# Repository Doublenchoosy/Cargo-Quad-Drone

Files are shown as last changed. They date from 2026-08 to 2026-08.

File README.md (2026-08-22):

# Printable frame parts

Three parts, sized to the exact components from the shopping list:

- **center_plate** — mounts the SpeedyBee F405 V4 stack (30.5mm hole pattern) and cradles the inboard end of each carbon tube arm.
- **motor_mount** — print 4 of these. Clamps to the outboard end of each tube and has the 19x19mm M3 bolt pattern for the iFlight 3112 motor, plus a center hole for the motor wires.
- **payload_deck** — carries the Raspberry Pi (standard 58x49mm hole pattern) on standoffs run down through the same 30.5mm pattern as the center plate, so one style of M3 standoff works the whole stack.

## Print settings
- Material: PETG (handles vibration and heat better than PLA — motors and ESCs get warm)
- Walls: 4 (center_plate, motor_mount — these carry flight loads), 3 is fine for payload_deck
- Infill: 25-30% gyroid or grid for center_plate/motor_mount, 15% for payload_deck
- Orientation: print flat as-is, no supports needed
- Consider M3 heat-set inserts for the stack and motor bolt holes if you'll be removing those screws often — not needed for the small zip-tie holes

## Tube arms
Get the **10x12x440mm** carbon tube (12mm OD), 4 pieces. Dry-fit the center plate and all 4 motor mounts on the tubes first, slide the motor mounts in/out until the motor-to-motor diagonal spacing is around 580-620mm, then mark, add a dab of thick CA glue or epoxy in each cradle groove, and zip-tie both ends of every tube through the small holes flanking the groove. Let the glue cure before your first flight. 330mm leaves about 70mm of slack per tube for this tuning step — no need for the longer 420mm version.

## Files
- `*.scad` — source, editable in the free OpenSCAD app if any of your actual parts differ slightly (open the file, change the variable at the top, e.g. `stack_span`, and re-render)
- `*.stl` — ready to slice and print as-is

## DYS F7 F772 Wire orientation
Screenshot 2026-08-21 at 11 17 44 PM

## AM32 ESC Wire orientation
Screenshot 2026-08-21 at 11 25 01 PM

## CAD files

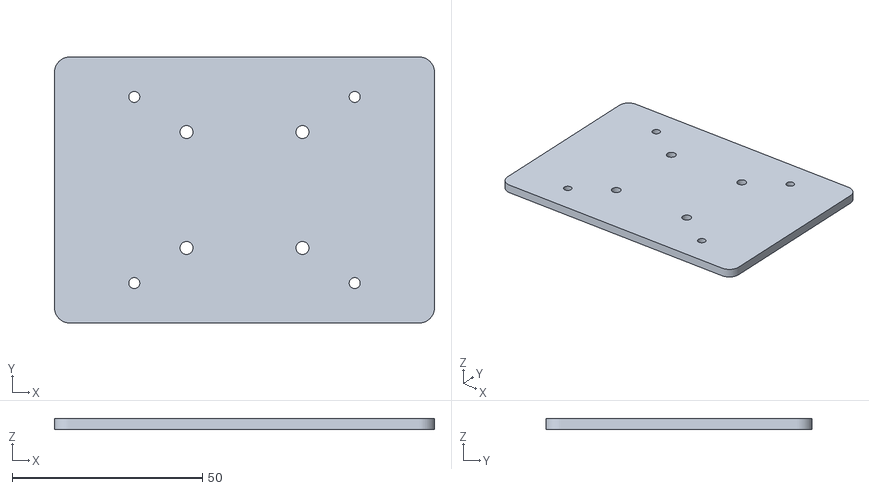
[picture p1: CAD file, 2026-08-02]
payload_deck.stl
100.0 x 70.0 x 3.00

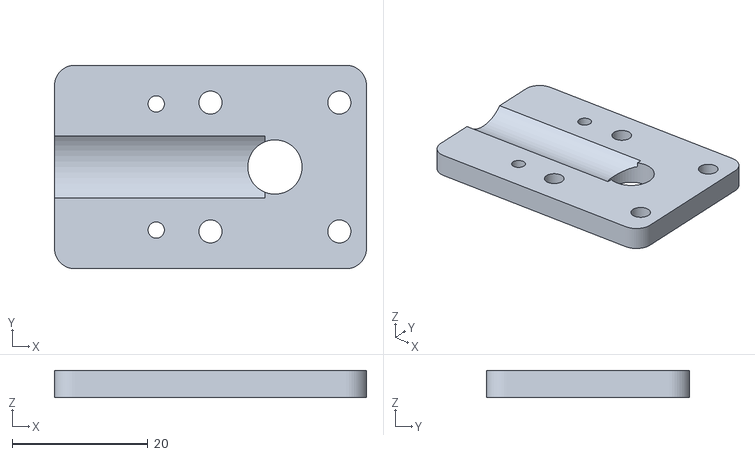
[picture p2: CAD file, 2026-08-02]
motor_mount.stl
46.0 x 30.0 x 4.00

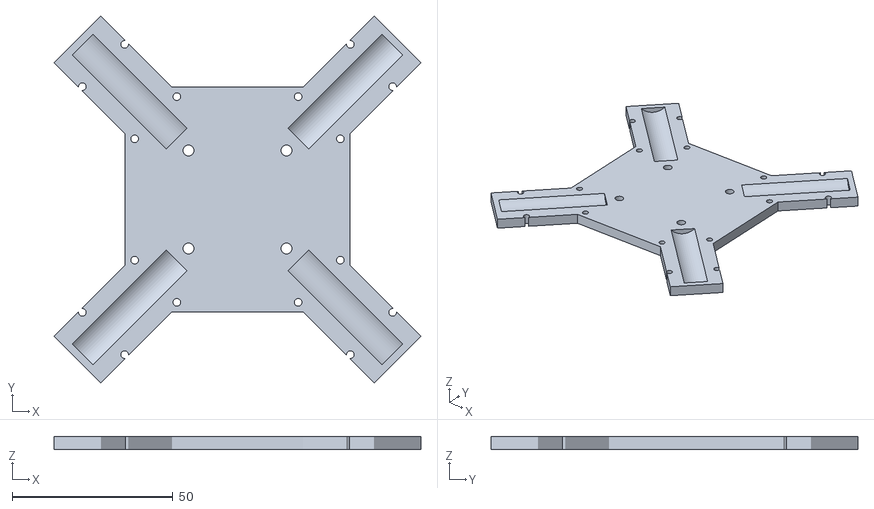
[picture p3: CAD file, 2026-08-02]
center_plate.stl
114.3 x 114.3 x 4.00

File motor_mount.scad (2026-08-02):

$fn = 48;

// ---- Parameters ----
plate_t      = 4;
tube_d       = 12.6;
mount_span   = 19;    // iFlight NIDICI 2812 motor bolt pattern (19x19mm)
motor_hole_d = 3.4;   // M3 clearance
wire_hole_d  = 8;      // center hole for motor wires
plate_len    = 46;     // length of the mount plate (tube clamp + motor face)
plate_w      = 30;     // wide enough for the 19mm motor bolt pattern with edge margin
groove_depth = 2;

module base_plate() {
    hull() {
        for (x = [-1,1]) for (y = [-1,1])
            translate([x*(plate_len/2-3), y*(plate_w/2-3), 0])
                cylinder(r=3, h=plate_t);
    }
}

module tube_channel() {
    translate([-plate_len/2 + plate_w/2, 0, plate_t - groove_depth + tube_d/2])
        rotate([0,90,0])
            cylinder(d=tube_d, h=plate_w+2, center=true);
}

module tie_holes() {
    for (yp = [-1,1])
        translate([-plate_len/2 + plate_w/2, yp*(tube_d/2+3), -1])
            cylinder(d=2.4, h=plate_t+2);
}

module motor_holes() {
    mx = plate_len/2 - mount_span/2 - 4;
    for (x = [-1,1]) for (y = [-1,1])
        translate([mx + x*mount_span/2, y*mount_span/2, -1])
            cylinder(d=motor_hole_d, h=plate_t+2);
    translate([mx, 0, -1])
        cylinder(d=wire_hole_d, h=plate_t+2);
}

difference() {
    base_plate();
    tube_channel();
    tie_holes();
    motor_holes();
}

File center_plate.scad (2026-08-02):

$fn = 48;

// ---- Parameters (edit these to match your exact parts) ----
plate_t     = 4;      // plate thickness (mm) - PETG recommended
hub         = 70;     // central hub square size (mm)
stack_span  = 30.5;   // SpeedyBee F405 V4 stack hole spacing (mm)
mount_d     = 3.4;    // M3 clearance hole
root_len    = 46;     // length of each arm root stub, from hub edge (mm)
tube_d      = 12.6;   // 12mm carbon tube OD + printing fit clearance
stub_w      = tube_d + 8;  // width of each root stub
tie_d       = 2.4;    // zip-tie hole diameter
wall_case   = 3;       // corner rounding radius

module hub_plate() {
    hull() {
        for (x = [-1,1]) for (y = [-1,1])
            translate([x*(hub/2-wall_case), y*(hub/2-wall_case), 0])
                cylinder(r=wall_case, h=plate_t);
    }
}

module arm_stub(angle) {
    rotate([0,0,angle])
        translate([hub/2*0.7, -stub_w/2, 0])
            cube([root_len, stub_w, plate_t]);
}

module stack_holes() {
    for (x = [-1,1]) for (y = [-1,1])
        translate([x*stack_span/2, y*stack_span/2, -1])
            cylinder(d=mount_d, h=plate_t+2);
}

// shallow cradle groove, not a full-depth cut, so the plate stays structurally intact
groove_depth = 2;
module tube_channel(angle) {
    rotate([0,0,angle])
        translate([hub/2*0.7 + root_len/2, 0, plate_t - groove_depth + tube_d/2])
            rotate([0,90,0])
                cylinder(d=tube_d, h=root_len*0.9, center=true);
}

module tie_holes(angle) {
    rotate([0,0,angle]) {
        for (xp = [hub/2*0.7 + root_len*0.25, hub/2*0.7 + root_len*0.75])
            for (yp = [-1,1])
                translate([xp, yp*(tube_d/2+3), -1])
                    cylinder(d=tie_d, h=plate_t+2);
    }
}

difference() {
    union() {
        hub_plate();
        for (a = [45,135,225,315]) arm_stub(a);
    }
    stack_holes();
    for (a = [45,135,225,315]) {
        tube_channel(a);
        tie_holes(a);
    }
}

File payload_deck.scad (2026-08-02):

$fn = 48;

// ---- Parameters ----
plate_t     = 3;
deck_len    = 100;
deck_w      = 70;
pi_span_x   = 58;    // Raspberry Pi mounting hole spacing (long axis)
pi_span_y   = 49;    // Raspberry Pi mounting hole spacing (short axis)
pi_hole_d   = 2.9;   // M2.5 clearance
stack_span  = 30.5;  // matches center_plate.scad, same standoffs run top to bottom
stack_hole_d = 3.4;
corner_r    = 4;

module deck() {
    hull() {
        for (x = [-1,1]) for (y = [-1,1])
            translate([x*(deck_len/2-corner_r), y*(deck_w/2-corner_r), 0])
                cylinder(r=corner_r, h=plate_t);
    }
}

module pi_holes() {
    for (x = [-1,1]) for (y = [-1,1])
        translate([x*pi_span_x/2, y*pi_span_y/2, -1])
            cylinder(d=pi_hole_d, h=plate_t+2);
}

module standoff_holes() {
    for (x = [-1,1]) for (y = [-1,1])
        translate([x*stack_span/2, y*stack_span/2, -1])
            cylinder(d=stack_hole_d, h=plate_t+2);
}

difference() {
    deck();
    pi_holes();
    standoff_holes();
}

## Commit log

2026-08-22 Update carbon tube length in README
2026-08-22 Add wire orientation section to README
    Added section on DYS F7 F772 wire orientation with image.
2026-08-22 Revise motor mount details and add ESC orientation
    Updated motor mount specifications and added ESC wire orientation section.
